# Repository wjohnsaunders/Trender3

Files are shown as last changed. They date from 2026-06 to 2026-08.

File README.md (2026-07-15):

# Trender3

## Introduction

The Trender3 is a printer that can be constructed (mostly) with the parts
from two Ender3s. You will need two additional 2020x290 V-slot extrusions
for the Y axis.

The Trender3 is a custom Voron Trident configured for a 170x170x180 build
volume, with 370x370x420 outer frame dimensions (not including the height
due to feet and skirts). While everything is contained within the outer
frame dimensions, you will need to print a top-hat if you intend to use a
top panel, due to the reduced clearance above the extruder.

Note: A normal 170x170x180 Trident would 410mm between the deck and the top
panels, whereas the Trender3 is 380mm due to the extrusion sizes we have
from the Ender3's. That 30mm loss makes the space above the extruder too
tight for the bowden tube.

## BOM

### Basic BOM
The BOM essentially consists of:
- Two older Ender3s disassembled into parts
- Voron Trident Configurator speced for 170x170x180 (less the parts described below)

### Steppers / Leadscrews
For the A/B steppers you can use the Ender3's extruder steppers (42-40). Make
sure they are the ones with a removable gear and a D shaft. If not you would
need to source some suitable steppers.

For the Z steppers, you can use the X,Y or Z steppers, find 3 that are the same
size (42-34). You don't need a D shaft, or a long shaft, you just need to be able
to remove the pulley/gear from the end. You should have 2 leadscrews and 2 couplers
from the Ender3's, you will need to buy 1 more leadscrew and 1 more Creality style
coupler.

You will need to buy the 3 leadscrew nuts from the Trident BOM, as the Ender3 ones
are not compatible.

Important: Make sure to get leadscrews and nuts with an 8mm lead (4 starts).

### Linear Rails

You will need to buy 3 x MGN12H 220mm and 3 x MGN12H 235mm. The Z axis rails
are 5mm longer than spec so you may not need a spacer/stopper at the top of
the rail (depend on the mix of R1/R2 parts you use). Note: it is recommended
to use a Z2 tolerance rail for X, then Z1 for the others. However Z0 for the
Z axis rails is good as well.

You will need community remixed parts for the MGN12H rails. There are remixes
available for Trident R1 and also for R2, so take your pick.

### PSU and Power Switch

The Ender3 power switch/connector and cord can be reused for mains power. I
have a skirt designed specifically for it.

The 24V 360W PSU from the Ender3 can be used. Both the Meanwell and the other
version fits. If you move to a mains power heated bed you could swap for a lower
power PSU from the Trident BOM. However if you retain the Ender3 heated bed you
will need the power.

## Frame

Refer to the following diagram that shows how the extrusions fit together.

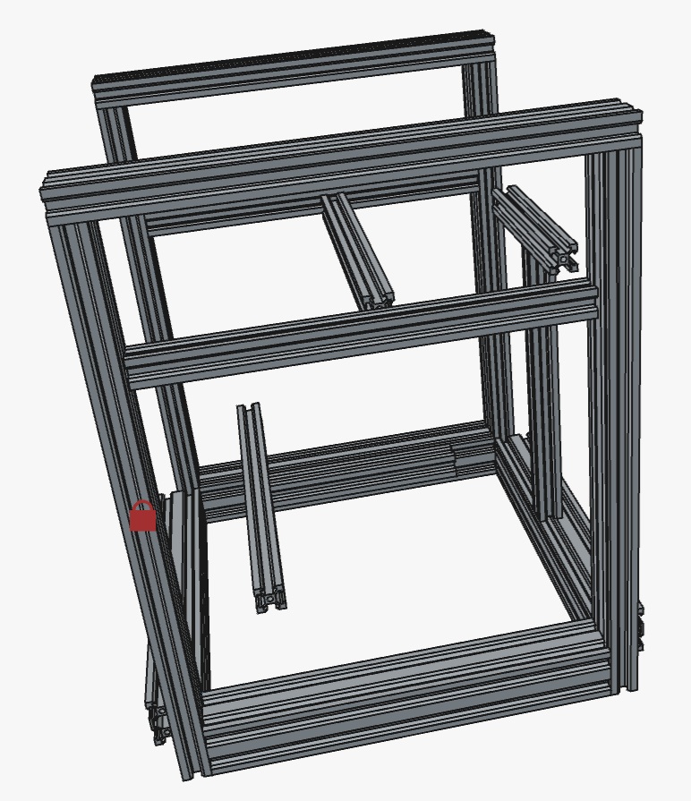
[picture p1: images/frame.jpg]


The 4040 and 2040 Ender3 extrusions are used as-is. However the 4 x 2020
extrusions need to be cut. Cut 1 down to 290mm, and 2 down to 250mm. The last
one should be cut into a 152mm length and a 160mm length. You will need 2
additional 290mm lengths of 2020 for the Y axis, which needs to be sourced
separately. Optionally 2 additional 290mm extrusions to brace the top of
the frame, and make panel installation straightforward.

The frame should be constructed using the blind joint method. Take care to
ensure that the frame is square before a final tighten of the bolts.

You should peel of any rubber feet from the Ender3 extrusions, these will not
be needed and they get in the way of aligning the frame.

Take the time to get the frame correct before starting to attach parts to it.

## X/Y/Z motion Systems

Follow the Trident assembly manual to install all of the parts. The use of
2040 and 4040 extrusions in the frame should not interfere with the install
of the standard Voron Trident parts.

## Heated Bed Options

### Ender3 Bed
The most cost effective approach is to re-use an Ender3 bed. You will not be
able to use all of the bed, however it is still functional for 170x170 prints.

The Ender3 bed should just fit between the front leadscews (tested with R1 Z
axis parts). You will need to replace the large wheel nuts with smaller thumb
(knurled) nuts from the Trident BOM (or just M4 nuts in a pinch).

You will need to drill 2x4mm holes in the X shaped plate that the bed attaches to.
A special tool has been provided to provide a precise drilling location. Drill the
first hole with a 4mm drill in the position as shown in the following picture.

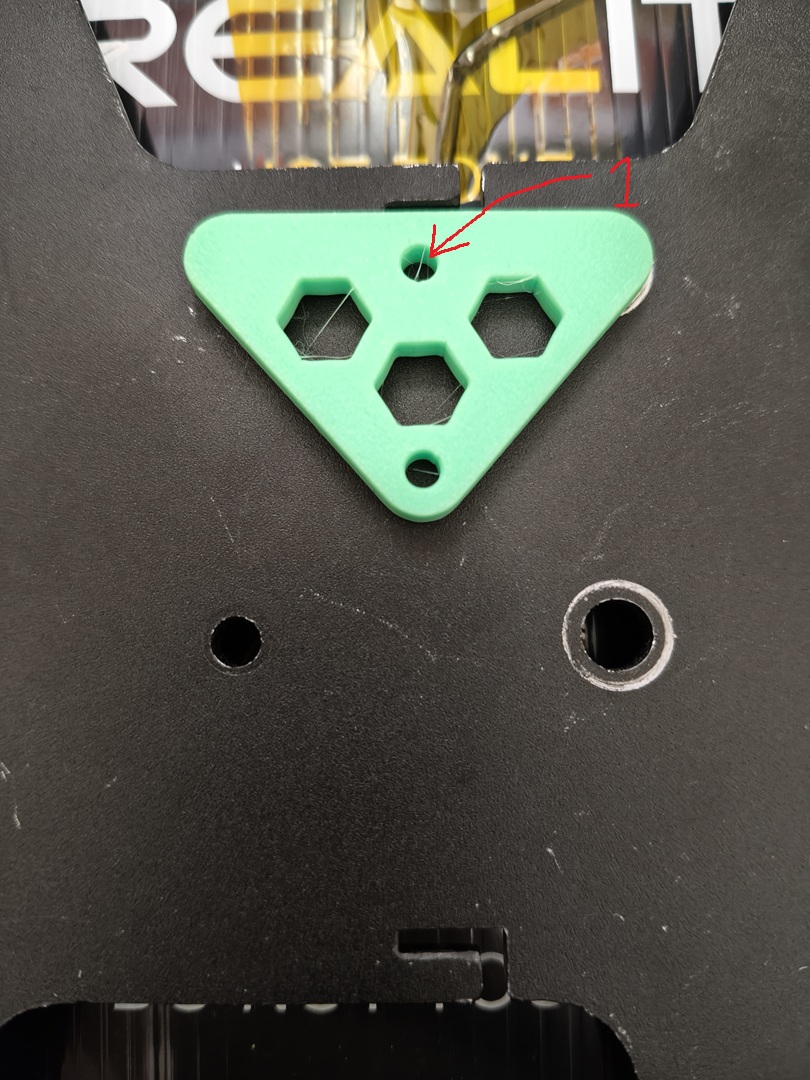
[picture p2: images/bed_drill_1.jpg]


Drill the second hole with a 4mm drill in the position as shown in the following
picture.

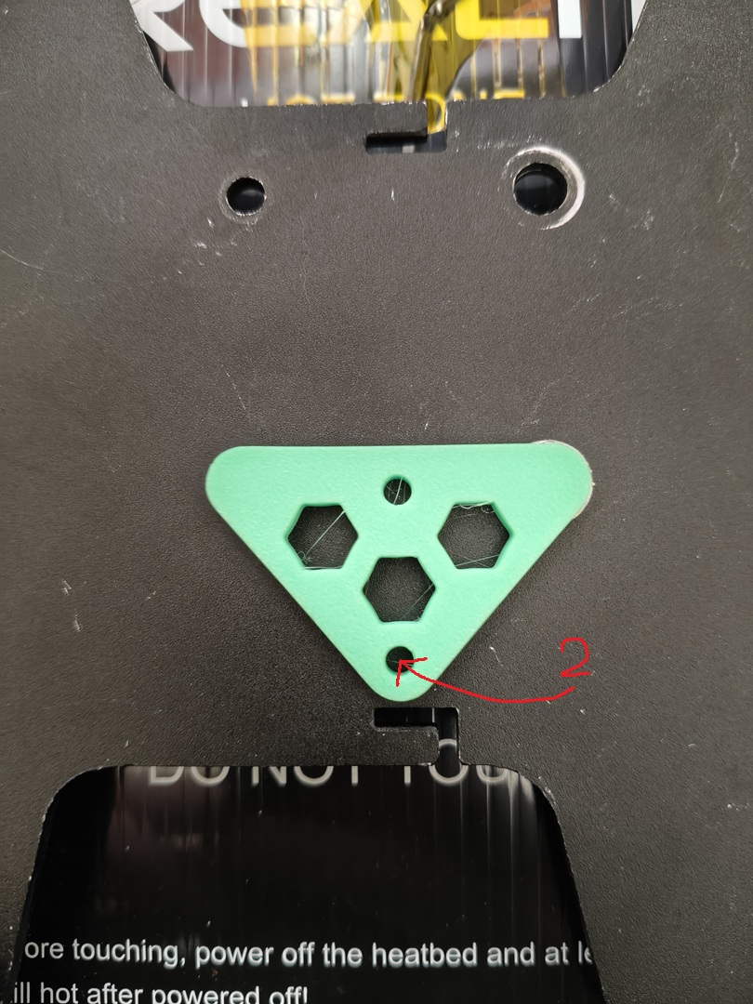
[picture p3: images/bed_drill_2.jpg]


Use M4 bolts and T-nuts from the Ender3 parts box to mount to the extrusion that
runs front to back. You can adjust the position of the bed to your preference,
just make sure that it doesn't hit anything when the Z axis moves.

### MIC-6 Bed

The recommended heated bed is for a 180x180 Salad Fork 3d printer, which is
available from AliExpress along with a silicon heater and PEI build plate. It
is common to see these beds sold with mounting holes for both the Salad Fork
180 and Micron 180 printers.

In the prefered bed position, the front mounting holes will not be aligned with
the extrusion so a bracket is needed. I haven't yet tackled this so I don't have
a solution. I am wondering if a 3D print would handle the heat, but I would like
to come up with a metal bracket.

## Electronics Bay Management

I have gone with the standard Trident DIN rail configuration. I didn't need a
5V supply for the Raspberry Pi as the Fysetc Spider H7 includes a Pi power
cable. Everything is a tight fit, but it does fit.

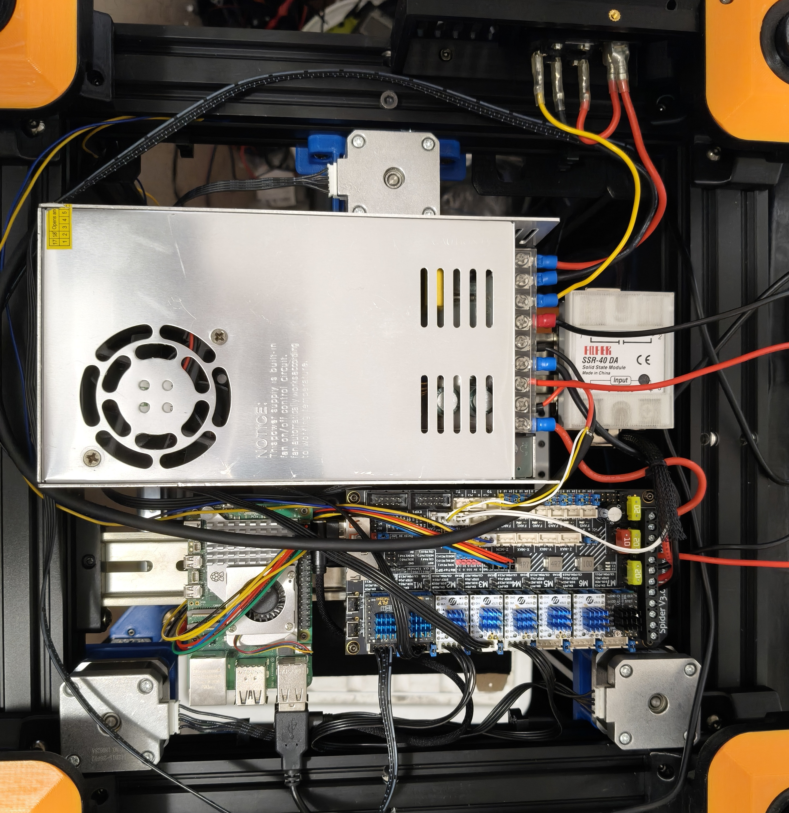
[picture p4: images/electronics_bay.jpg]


There is be an additional 20mm of height in the electronics bay due to the use
of 4040 extrusion. So more space is available if you go up. A mount for the
Raspberry Pi that rotates it 90 degrees would make the fitment less tight.

If I were to do an inverted electronics mod in the future, I would likely go
with an "FT EMS" panel approach to allow flexible placement of different brands
of components. I had a good experience with that on a Duender, and it is used
on Vorons in place of the DIN rails.

## Final thoughts

I have found that Feet and Skirts from "doom cubes" are good inspiration for
what the Trender3 needs. However the small size means that the skirts will not
fit as-is. I have a progressing design for custom skirts and feet for this
project. Some of the skirts are ready now, and I have borrowed some feet that
gets the job done for now.

The toolhead choice is left up to the builder to decide. There are a number
of good choices available for the smaller printers. Just don't make yet
another StealthBurner like I did, so it does work if you insist.

I would recommend an umbilical with a CAN/USB toolhead PCB, to avoid cramming
so many cable chains into something so small. I prefer a swing-arm to support
the umbilical. However there are many Trident solutions to this problem, and
this is a Trident after all, so experiment.

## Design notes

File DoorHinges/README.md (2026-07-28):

# Door Hinges

These door hinges are designed to fit to a 2040 (or 4040) V-Slot extrusion and
allow for the door to swing open 270 degrees and clear panels and panel clips
(7mm clearance provided - which is a Trident 4mm panel clip).

Rather than use adhesive tape, they are designed for holes to be drilled in the
panels, with the hinge screwed on using a reinforcement part to sandwitch the
panel and prevent it cracking.

# Printing

Print 2 or 3 sets for the left, 2 or 3 sets for the right, and the appropriate
number of reinforcement parts.

There are a couple of drill jigs that you can print to guide hole drilling. The
end jig provides 16mm from the edge of the panel (6mm is the overlap of the
extrusion, and 10mm for spacing). However you can use the other jig to place
the holes wherever you want them. Just measure and check clearance to any
other parts that you might have before drilling. If your panel clips are
thicker than 7mm, you might want to position the hinges away from them.

# BOM

4 or 6 3mm x 35mm pins (down to 25mm should still work)
4 or 6 M3x8 SHCS
4 or 6 M4 hammer nuts
8 or 12 M3x8 BHCS

# Assembly

The holes are designed so that the pins are a tight fit into the extrusion
mounts, and a looser fit into the hinge that attaches to the panels. That
allows you to take the doors off and the pins stay in place. That means
you will have to tap the pins into place with a tool.

Use the SHCS and hammer nuts to attach the extrusion mounts loosely.

Use the jig to drill the holes in the panel. Check twice between drilling.
You may want to mock up the positions by using sticky tape first, then drill
when you are satisfied the doors will open properly.

Attach the hinge to the panel by sandwiching the panel between it and the
reinforcement part, use the BHCS to attach. Don't screw down too hard,
just tight is enough.

Fit the doors onto the pins. Adjust the extrusion mount position so that the
doors are positioned correctly, aligned with each other and open smoothly.

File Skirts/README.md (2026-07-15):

# Trender3 Skirts

The skirts are a redesign that moves away from the Trident hexagons.
The additional difference is that the side skirts have the same look
as the front/rear skirts, which allows fingers to grip the sides for
carrying the printer.

I initially wanted to only do a left and rigth skirt from the back and
sides. However a prototype print showed that it was very hard to install
the second skirt, so I went with 3 skirts per side. The up-side was that
the front left/right skirts could also serve the sides, reducing the
number of designs that I needed to do.

## Front

### Print BOM

- 1x Trender3Skirts-MkII-FrontAndSidesStyleA
- 1x Trender3Skirts-MkII-FrontAndSidesStyleB

#### Headless Option
- 1x Trender3Skirts-MkII-CenterDoubleMountingBoltWidth117 (for headless)

#### Trident 12864 Option

- 1x mini12864_case_front
- 1x mini12864_case_rear
- 1x [a]_mini12864_case_front_insert
- 1x [a]_mini12864_case_hinge

Note: Files from Trident STL package

### Description

I have kept the center available for one of the Trident screen options.
Hopfully any screen that fits in the standard space on a Trident will fit.
There is also a no-screen skirt that keeps the Trender3 style for headless
builds.

Measurements: 268 (243 not including the feature)
Front Left/Right width: 75 (62.5 not including the feature)
No-screen skirt width: 117
Trident screen mount width: 117

## Sides

### Print BOM

- 2x Trender3Skirts-MkII-FrontAndSidesStyleA
- 2x Trender3Skirts-MkII-FrontAndSidesStyleB

#### Single Fan Option

- 1x Trender3Skirts-MkII-FanMount60mm
- 1x Trender3Skirts-MkII-FanCarrier60mm
- 1x Trender3Skirts-MkII-FanGrill60mm
- 1x Trender3Skirts-MkII-CenterDoubleMountingBoltWidth113

#### Dual Fans Option

- 2x Trender3Skirts-MkII-FanMount60mm
- 2x Trender3Skirts-MkII-FanCarrier60mm
- 2x Trender3Skirts-MkII-FanGrill60mm

### Description

The front left/right skirts are re-used, and the center skirt carries the
fan. There is a fan option for the standard 6020 Trident fan, but also for
dual 4010 axial fans as used on the Ender3 for the electronics bay cooling
and the hotend cooling.

Measurements: 264 (239)
Front Left/Right width: 75 (62.5 not including the feature)
Fan skirt width: 113

## Back

### Print BOM

- 1x Trender3Skirts-MkII-LeftSideRear-Ender3
- 1x Trender3Skirts-MkII-RightSideRear
- 1x Trender3Skirts-MkII-CenterSingleMountingBoltWidth41

### Description

The back of the Trender3 has a skirt with cutouts for the Ender3 inlet.
It has a narrow center skirt in addition to the right side skirt. It is
the only side that doesn't follow the narrow sides and wide center style,
but it is discated by needing an inlet, and a center inlet is blocked by
the rear stepper.

Measurements: 268 (243 not including the feature)
Back Left/Right width: 113 (100.5 not including the feature)
Back Center width: 41

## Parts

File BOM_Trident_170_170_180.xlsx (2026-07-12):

Category | Description | Qty | Notes
Fasteners | 2020 Drop-in T-nut, M5 | 69
 | M5x40 BHCS | 4
 | M5x30 BHCS | 4
 | M5x16 BHCS | 58
 | M5x10 BHCS | 45
 | M5 1mm Spacer | 24
 | M5xD7xL6 Heat Set | 15
 | M4x6 BHCS | 7
 | M4 Knurled Nut | 3
 | M3x50 SHCS | 2
 | M3x40 SHCS | 9
 | M3x30 SHCS | 13
 | M3x25 SHCS | 10
 | M3x20 SHCS | 3
 | M3x16 SHCS | 27
 | M3x12 SHCS | 73
 | M3x8 SHCS | 128
 | M3x6 BHCS | 59
 | M3x10 FHCS | 2
 | M3x6 FHCS | 17
 | M3 Locknut | 6
 | M3 Washer | 4
 | 2020 Drop-in T-nut, M3 | 74
 | M3 Hammerhead T-Nut | 55
 | M3xD5xL4 Heat Set | 109
 | M2x10 Selftapping screw | 17
Motion | GT2 20T Pulley (5mm ID 6mm W) | 3
 | GT2 20T Toothed Idler (5mm ID 6mm W) | 2
 | F695 Bearing | 26
 | GE5C Spherical Bearing | 3
 | TR8x4 Leadscrew Nut | 3
 | 5x30mm Shaft | 1
 | BMG Extruder Components Kit | 1
 | Linear Rail MGN12H 220mm | 1 | X
 | Linear Rail MGN9H 220mm | 2 | Y
 | Linear Rail MGN9H 230mm | 3 | Z - 235mm
 | GT2 Open Belt LL-2GT-6 (6mm wide) - 1370mm | 2
Vibration Management | Rubber Foot | 4
Electronics | NEMA17 Motor 17HS19-2004S | 2
 | SPDT KW10 Limit Micro Switch | 3
 | Omron TL-Q5MC2 - NPN, NC, 5mm Sense Inductive Probe | 1
 | E3D V6 Bowden Hotend Kit (24V) | 1
 | 50x50x15 Centrifugal Fan (24V) | 1
 | 40x40x10 Axial Fan (24V) | 1
 | Mini 12864 Display | 1
 | Medium Blow Fuse 5 x 20mm: 4A for 220V mains or 8A for 120v | 2
 | TycoElectronics 10EGG1-2 Filtered Power Inlet | 1
 | ZF - Rocker Switches DPST 16A | 1
 | Keystone CAT6 Insert (Optional) | 1
 | 60x60x20 Fan (24V) | 3
 | 6 Stepper Controller (or multiple to equal 6+ steppers) | 1
 | TMC2209 Stepper Motor Driver | 6
 | Raspberry Pi 4 | 1
 | Mean Well LRS-200-24 PSU | 1
 | Mean Well TBC-09 Terminal Cover | 1
 | Mean Well RS-25-5 PSU | 1
 | Omron G3A-210B-DC5 SSR | 1
 | DIN Rail Mount Bracket for G3A SSR | 1
 | BAT85 Diode | 1
 | C13 Power Cord | 1
 | Thermal Fuse (150C) | 1
 | NEMA14 Motor 36STH20-1004AHG | 1
 | NeoPixel RGBW Mini Button PCB | 3
 | NEMA17 TR8x4 230mm Linear Stepper | 3 | Use leadscrews and couplers
Misc | PTFE Tube (4mm OD 2mm ID | Toolhead) - 1m | 1
 | 3M VHB Tape 5952 | 1
 | Single Sided Foam Tape (3mm Thick, 5-6mm Wide) | 9
 | Loctite Blue Threadlocker Stick | 1
 | Mobil EP2 Grease | 1
 | Tesa Wire Loom Harness Tape | 1
 | 6x3mm Neodymium Magnet | 8
 | PTFE Tube (4mm OD 3mm ID) - 1m | 1
Cables | Nylon Cable Ties 4" | 40
 | 1/2" Braided Cable Sheathing (ft) | 5
 | 18AWG High-Flex Wire (ft) | 10
 | 20AWG High-Flex Wire (ft) | 10
 | 22-24AWG High-Flex Wire (min 19 strand)(ft) | 100
 | Spade Crimp Terminal 4.8mm Female | 10
 | JST XH Connector Plug 4 Position | 5
 | JST XH Connector Plug 3 Position | 4
 | JST XH Connector Plug 2 Position | 2
 | JST XH Female Pin | 40
 | MicroFit3 Connector Plug 4 Position | 2
 | MicroFit3 Connector Plug 3 Position | 1
 | MicroFit3 Connector Plug 2 Position | 5
 | MicroFit3 Connector Receptacle 4 Position | 2
 | MicroFit3 Connector Receptacle 3 Position | 1
 | MicroFit3 Connector Receptacle 2 Position | 5
 | MicroFit3 Female Pin | 40
 | MicroFit3 Male Pin | 40
 | 10x11 Cable Chain - 1m, 3 End Sets | 1
 | WAGO 221-415 Lever-Nuts | 3
 | WAGO 221-412 Lever-Nuts | 3
Frame | DIN 3 Rails (35mm W) - 290mm | 2
 | Misumi HFSB5-2020-430-LCP-RCP-AV290 | 4 | 2040x400 (frame corners)
 | Misumi HFSB5-2020-290-TPW | 3 | 4040x290 (frame lower front/sides)
 | Misumi HFSB5-2020-290-AH145-TPW | 1 | 4040x290 (frame lower back)
 | Misumi HFSB5-2020-290-TPW | 2 | 2020x290 (Y axis)
 | Misumi HFSB5-2020-290-TPW | 2 | 2040x330 (frame top sides)
 | Misumi HFSB5-2020-290-TPW | 2 | 2020x290 (frame top front/back)
 | Misumi HFSB5-2020-260-LTP | 1 | 2020x260 (Z axis back)
 | Misumi HFSB5-2020-160 | 1 | 2020x160 (A/B connector back)
 | Misumi HFSB5-2020-250 | 1 | 2020x250 (X axis)
 | Misumi HFSB5-2020-152-LTP | 1 | 2020x152 (bed 1)
 | Misumi HFSB5-2020-290-AH145 | 1 | 2020x290 (bed 2)
Panels | ~~Coroplast Sheet - 289x289x4 mm~~ | 2 | 289x289x4mm | deck/bottom
 | ~~Coroplast Sheet - 302x402x4 mm~~ | 1 | 302x372x4mm | rear
 | ~~Acrylic Sheet Clear - 151.5x403x3 mm~~ | 2 | 151.5x373x3mm | front doors
 | ~~Acrylic Sheet Clear - 303x403x3 mm~~ | 2 | 303x373x3mm | sides
 | ~~Acrylic Sheet Clear - 303x303x3 mm~~ | 1 | 303x303x3mm | top
Buildplate | 3M 468MP Adhesive Sheet - 7"x7" | 1 | 180x180 Saladfork/Micron
 | PEI 0.04" Sheet - 7"x7" | 1
 | MIC6 5/16" Plate - 7"x7" | 1
 | Keenovo Silicone AC Heater w/ thermistor - 120x120mm (200W) | 1

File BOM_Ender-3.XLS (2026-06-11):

Ender-3 BOM
Part Code | Part Name | Specification | UNIT | Qty
200101027 | Control panel | 1284P | PCS | 1
200102010 | LCD |  | PCS | 1
400101002 | E plate | 2.5mm | PCS | 1
400101005 | Y Motor holder | 3mm | PCS | 1
400101006 | X Adjustment Block | 3mm | PCS | 1
400101027 | Z Stent | 3.0mm | PCS | 1
400101029 | Fan cover | 0.8mm | PCS | 1
400101081 | Support frame | 2.0mm | PCS | 1
400101103 | E motor bracket | 2.5mm，B1 | PCS | 1
400101104 | X motor bracket | 3mm，B1 | PCS | 1
400101130 | Sheetmetal enclosure bottom | 0.8MM | PCS | 1
400101131 | Sheetmetal enclosure top | 0.8MM | PCS | 1
400101133 | LCD support | 2MM | PCS | 1
400101007 | Y Adjustment Block | 3mm | PCS | 1
400101129 | Y plate | 4mm | PCS | 1
400102065 | 2020 Top Profile | 20*20-L330 | PCS | 1
400102066 | 2020 X Profile | 20*20-L345 | PCS | 1
400102067 | 2040 Y Profile | 20*40-L330 | PCS | 1
400102068 | 2040 Right Profile | 20*40-L400 | PCS | 1
400102069 | 2040 Left Profile | 20*40-L400 | PCS | 1
400102070 | 4040 Central Profile | 40*40-L250 | PCS | 1
400102071 | 4040 Left Profile | 40*40-L290 | PCS | 1
400102072 | 4040 Right Profile | 40*40-L290-2 | PCS | 1
400103001 | E gear | D11-40 | PCS | 1
400104004 | Heat block | 20*20*10 | PCS | 1
400105008 | Radiator | 12*20*27.8mm,2*M3 | PCS | 1
400106003 | nozzle | 0.4mm | PCS | 2
400107006 | Catheter | D7-M6-L28mm | PCS | 1
400108001 | Spacers for rollers | D8-d5-H-8.35mm | PCS | 11
400108002 | Eccentric column | D7.2-d5-H-8.35mm | PCS | 5
400201001 | 42-34 Motor | JK42HS34-0844YA-03F | PCS | 3
400201004 | 42-40 Motor | JK42HS40-1004AC-01F | PCS | 1
400202002 | 624U Pillow | 624U | PCS | 1
400202003 | F688ZZ Pillow | F688ZZ | PCS | 4
400202004 | 625ZZ Pillow | 625ZZ | PCS | 26
400204002 | Extrusion Spring | 1.1*8*L22 | PCS | 5
400205002 | M2*8 Socket Head Screw | M2*8 | PCS | 2
400205003 | M2*10 Socket Head Screw | M2*10 | PCS | 2
400205007 | M3*18 Socket Head Screw | M3*18 | PCS | 1
400205013 | M4*8Socket Head Screw | M4*8 | PCS | 7
400205014 | M4*10 Socket Head Screw | M4*10 | PCS | 2
400205015 | M4*16 Socket Head Screw | M4*16 | PCS | 4
400205018 | M3*3 screw | M3*3 | PCS | 4
400205019 | M4 screw | M4 | PCS | 4
400205021 | M3*4 Pan Head Screw | M3*4 | PCS | 1
400205029 | M3*6 Pan Head Screw | M3*6 | PCS | 18
400205031 | M3*10 Pan Head Screw | M3*10 | PCS | 12
400205032 | M3*16 Pan Head Screw | M3*16 | PCS | 5
400205044 | M5*8 Pan Head Screw | M5*8 | PCS | 8
400205053 | M5*30 Pan Head Screw | M5*30 | PCS | 10
400205055 | M5*40 Pan Head Screw | M5*40 | PCS | 3
400205060 | M3*10 Pan Head Screw | M3*10-P | PCS | 1
400205068 | M4*14 Pan Head Screw | M4*14-P | PCS | 2
400205074 | M4*35 Flush Head Screw | M4*35-P | PCS | 4
400205097 | M5 Self-locking nut | M5 | PCS | 13
400205098 | M8 Self-locking nut | M8 | PCS | 2
400205101 | M4 T-Slot Nut | M4T | PCS | 8
400205102 | M5 T-Slot Nut | M5T | PCS | 3
400205105 | M3 Split Washer | M3 | PCS | 6
400205106 | M4 Split Washer | M4 | PCS | 7
400205107 | M5 Split Washer | M5 | PCS | 12
400205109 | M5 washer | M5 | PCS | 5
400205110 | M5 washer1 | 5*8*1 | PCS | 13
400205111 | z nut | T8*8 | PCS | 1
400205122 | M4*20 Socket Head Screw | M4*20 | PCS | 3
400205140 | M4*18 Pan Head Screw | M4*18-P | PCS | 2
400205141 | M3*40 Pan Head Screw | M3*40-P | PCS | 4
400205144 | M3*18 Pan Head Screw | M3*18-P | PCS | 2
400205148 | M4*16 Screw |  | PCS | 5
400205153 | M3*6 Screw | M3*6 | PCS | 2
400205163 | M5*25 Socket Head Screw | M5*25 | PCS | 6
400205165 | M5*40 Socket Head Screw | M5*40 | PCS | 2
400205166 | M5*45 Socket Head Screw | M5*45 | PCS | 10
400205176 | M8*35 Pan Head Screw | M8*35 | PCS | 2
400206017 | Z threaded rod | T8*8-L365mm | PCS | 1
400208004 | Z coupler | D5*8 | PCS | 1
400210001 | Pneumatic joint | D4M8 | PCS | 1
400210002 | M6 Pneumatic joint | KJH04-06 | PCS | 2
400211009 | 2GT-pulley | 2GT-d5-20-6mm | PCS | 2
400212037 | X belt | 2M-W6-L786mm | PCS | 1
400212038 | Y belt | 2M-W6-L743mm | PCS | 1
400214001 | Copper cover | D8-0.8 | PCS | 4
400301008 | 24V15A power supply | 24V 15A | PCS | 1
400302026 | Hot bed | 24V，235*235mm，220W | PCS | 1
400303006 | Nozzle thermistor | D1.8-L1000mm-100K | PCS | 1
400303022 | Bed thermistor | D1.8-L700mm-100K | PCS | 1
400304001 | limit switch | 3PIN | PCS | 3
400305007 | power switch | 10A | PCS | 1
400306127 | Red silicone wire | 16号-L170mm | PCS | 1
400306128 | Yellow silicone wire | 18号-L170mm | PCS | 1
400306145 | Black silicone wire | 16号-L170mm | PCS | 1
400306217 | Hot bed line | 16号-L500mm | PCS | 1
400306221 | Red silicone wire | 16号-L90mm, | PCS | 1
400306222 | Main board line | 16号-L310mm,XT60 | PCS | 1
400306223 | power line | 16号-L170mm,XT60 | PCS | 1
400306224 | X,E Motor Line | Motor Line L670mm，Limit Line L750mm | PCS | 1
400306225 | Y Motor Line | L420mm | PCS | 1
400306226 | Z Motor Line | Motor LineL280mm，Limit Line L180mm | PCS | 1
400306228 | Display line | 10pin,L470mm | PCS | 1
400307001 | lcd Knob |  | PCS | 1
400308002 | Heater | 24V，40W-L1000MM，Φ6*20 | PCS | 1
400309032 | Cold section fan | 24V-4010-L1000-7600r | PCS | 1
400309044 | Nozzle fan | 24V-4010-L1000-5800r | PCS | 1
400309045 | Case fan | 24V-4010-L150mm | PCS | 1
400402010 | Z motor bracket |  | PCS | 1
400402020 | 2020 Endcap | 2020 | PCS | 2
400402023 | Nozzle fan duct |  | PCS | 1
400402028 | Power holder | 2mm | PCS | 1
400402032 | Y limit switch bracket | ABS | PCS | 1
400402033 | Z limit switch bracket | ABS | PCS | 1
400403003 | Rollers |  | PCS | 13
400403004 | Support tube |  | PCS | 1
400403005 | M30 Plastic nut | M30*6.5 | PCS | 2
400404030 | Hot bed wire bracket |  | PCS | 1
400404031 | Hot bed line support cover |  | PCS | 1
400404032 | E idler tensioner |  | PCS | 1
400404033 | E housing |  | PCS | 1
400404038 | X limit switch bracket | ABS | PCS | 1
400404040 | Hand Twisted Nut | D60mm | PCS | 4
400404041 | 4040 Endcap | ABS | PCS | 2
400406006 | Foot pads | 20*40mm*3mm | PCS | 4
400407013 | D4 Teflon tube | D4-d2-L400mm | PCS | 1
400409003 | Silk pole cover | T8*8 | PCS | 1
400501034 | Linear tube | W8-L450mm | PCS | 1
400501035 | Linear tube | W8-L950mm | PCS | 1
400504007 | Fan cover sticker |  | PCS | 1
400504008 | Product Qualification Certificate |  | PCS | 1
400505021 | Fiber board | 235*235*1.0mm | PCS | 1
400506001 | Scissor |  | PCS | 1
400506002 | shovel |  | PCS | 1
400506005 | 1.5# Hexagonal wrench inside |  | PCS | 1
400506006 | 2# Hexagonal wrench inside |  | PCS | 1
400506007 | 2.5# Hexagonal wrench inside |  | PCS | 1
400506008 | 3# Hexagonal wrench inside |  | PCS | 1
400506009 | 4# Hexagonal wrench inside |  | PCS | 1
400506011 | screwdriver |  | PCS | 1
400506016 | power cord |  | PCS | 1
400506020 | needle |  | PCS | 1
400506029 | tie | 4*150mm | PCS | 10
400506035 | 6# Open wrench |  | PCS | 1
400506036 | 8-10# Open wrench |  | PCS | 1
400506044 | Clip | 6#,15mm | PCS | 4
500101065 | Bubble cotton | 495*380*160mm | PCS | 1
500201001 | Self-Sealing bag | 6cm*9cm*0.8mm | PCS | 14
500201002 | Self-Sealing bag | 9cm*13cm*0.8mm | PCS | 1
500201004 | Self-Sealing bag | 15cm*20cm*0.8mm | PCS | 2
500201006 | Self-Sealing bag | 18cm*26cm*0.6mm | PCS | 1
500201008 | Prevention electrostatic bag | 15cm*20cm | PCS | 1
500301056 | paper box | 510*400*190mm | PCS | 1
500601001 | Opinion Card |  | PCS | 1
600101011 | Instruction |  | PCS | 1
600401004 | Memory Card | 8G | PCS | 1
600501001 | Card Reader |  | PCS | 1
600601016 | warranty card |  | PCS | 1
600601023 | Manufacture of numbered stickers | 60*10.4MM | PCS | 1
600601026 | Specification stickers | 65*40mm | PCS | 1
600601058 | Facebook code sticker | 41*41mm | PCS | 1
700206003 | Testing consumables | 5M | PCS | 1
700301044 | High temperature cotton | 20*50mm | PCS | 1
700301051 | gummed paper | 30*60 | PCS | 3
700301054 | gummed paper | 60*60mm | PCS | 1
700301056 | High temperature cotton | 50*60mm | PCS | 1

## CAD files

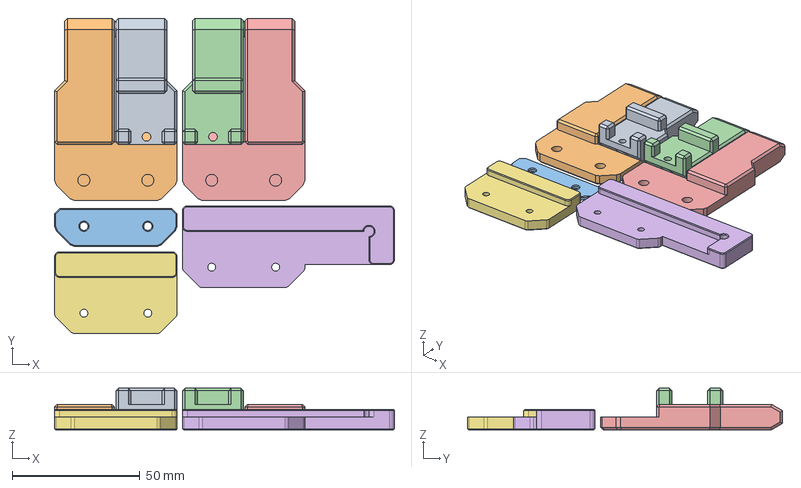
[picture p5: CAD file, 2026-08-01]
DoorHinges/CAD/DoorHinges2040.FCStd
133.0 x 123.3 x 16.3 mm
ExtrusionMountLeft
PanelMountLeft
PanelReinforcement
ExtrusionMountRight
PanelMountRight
DrillingJigEnds
DrillingJig

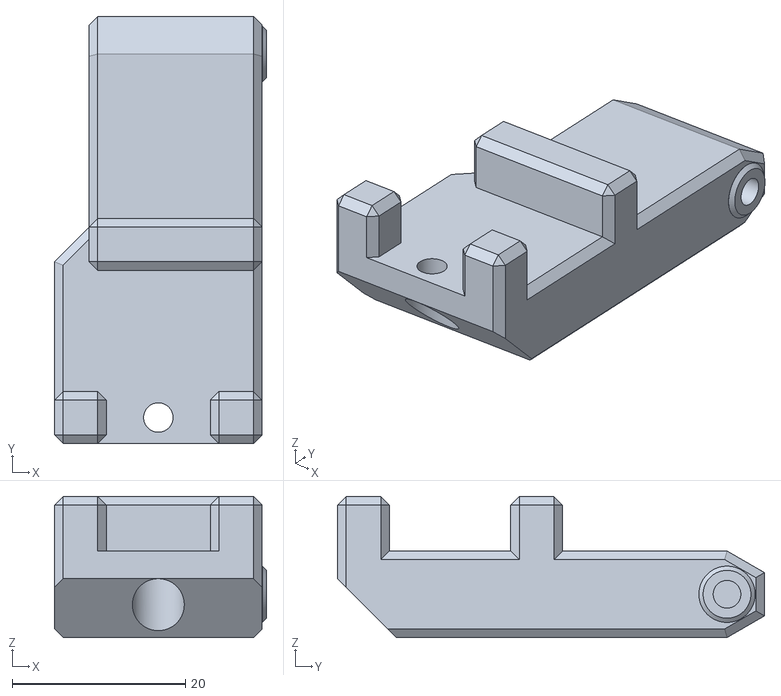
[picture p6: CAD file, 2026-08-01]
DoorHinges/STL/DoorHinges2040-ExtrusionMountRight.stl
24.5 x 49.3 x 16.3

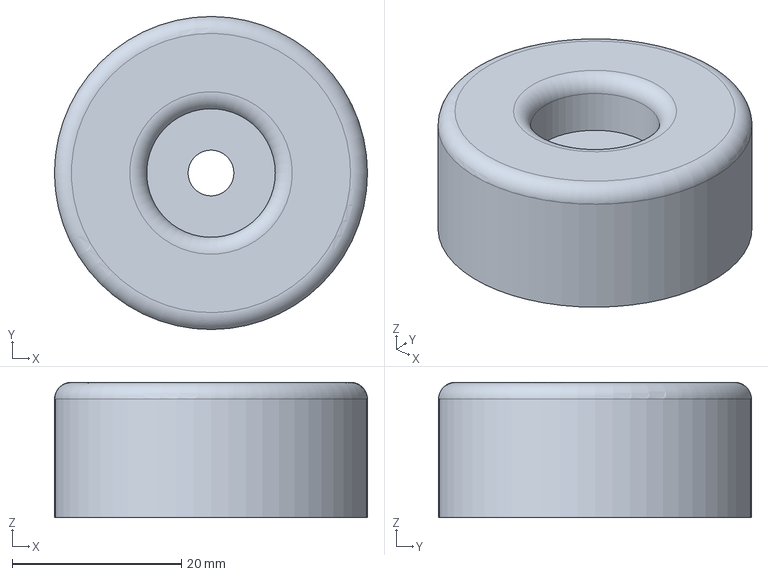
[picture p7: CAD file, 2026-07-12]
Skirts/CAD/TpuFeet.FCStd
37.0 x 37.0 x 16.0 mm

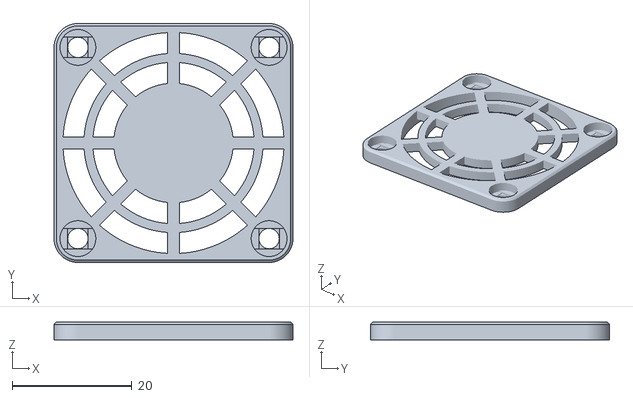
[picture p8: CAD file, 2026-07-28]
Skirts/STL/Trender3Skirts-MkII-FanGrill40mm.stl
40.0 x 40.0 x 3.00

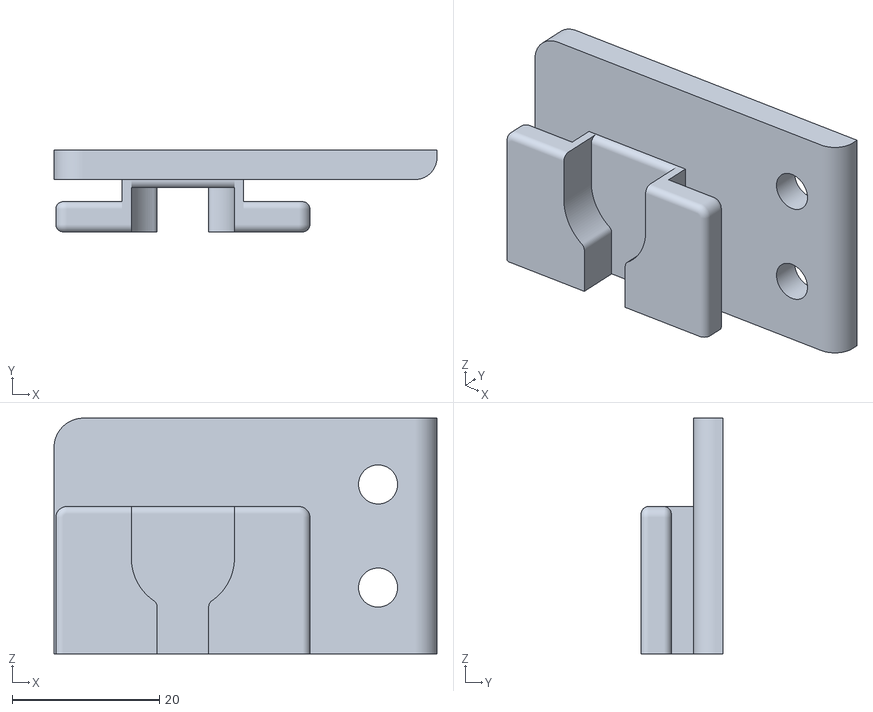
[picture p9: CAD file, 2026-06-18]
STL/ad5x-spool-holder-bracket-OffsetMountRight.stl
52.0 x 11.1 x 32.0

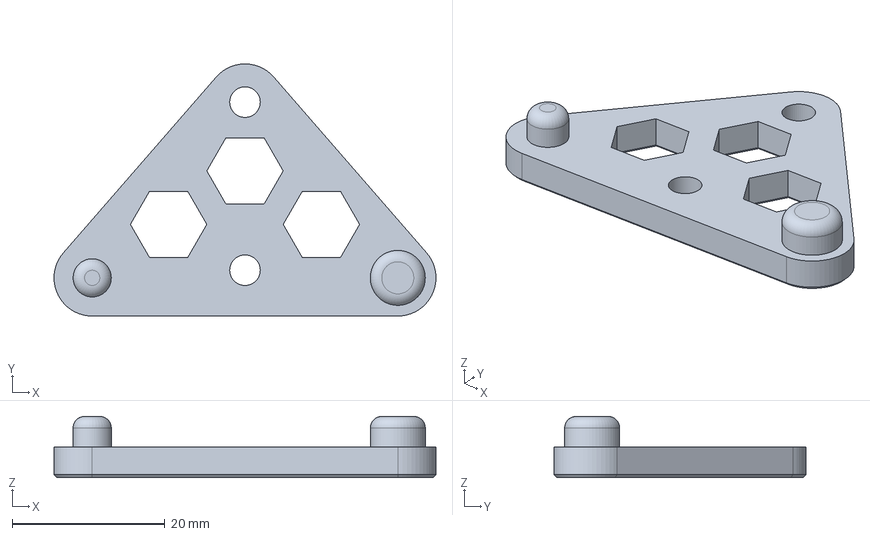
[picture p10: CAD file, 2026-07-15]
Tools/CAD/Ender3Bed.FCStd
50.0 x 33.0 x 8.00 mm

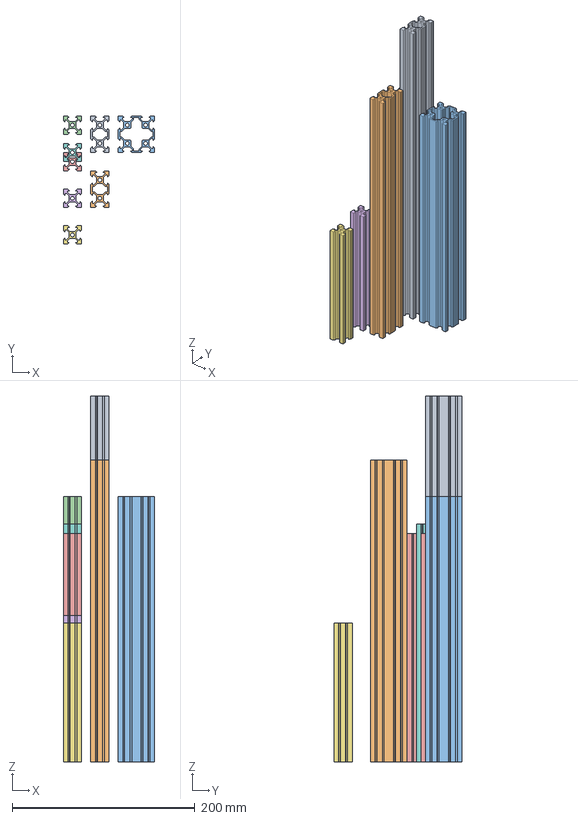
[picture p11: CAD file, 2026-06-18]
CAD/Trender3_Frame_Extrusions.FCStd
100.0 x 140.0 x 400.0 mm
2040x400 (uprights)
2040x330 (top left/right)
4040x290 (bottom left/right/front/back)
2020x290 (Y axis, bed 1)
2020x250 (X axis)
2020x160 (X/Y rear horizontal)
2020x152 (bed 2)
2020x260 (Z rear vertical)

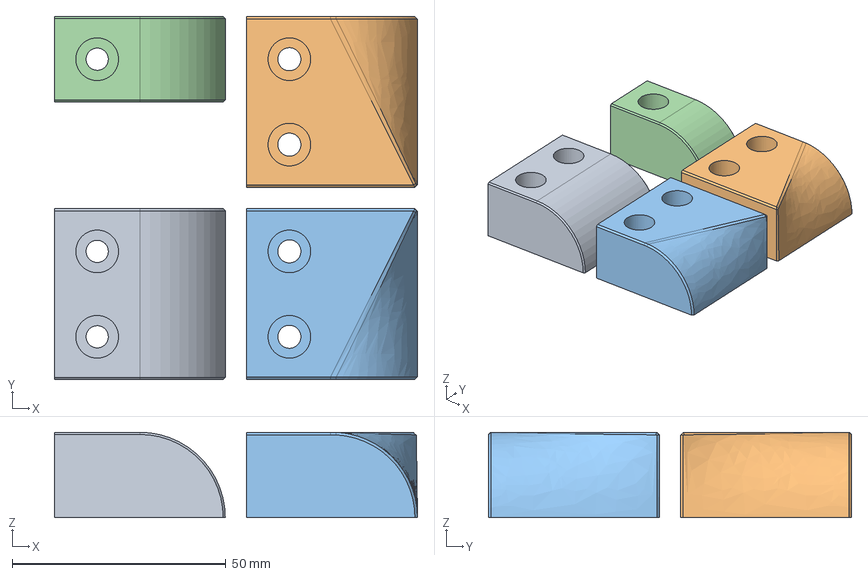
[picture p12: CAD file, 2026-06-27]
Skirts/CAD/CornerFinish.FCStd
85.0 x 85.0 x 20.0 mm
Bullnose4040
BlendSquareToBullnose_A
BlendSquareToBullnose_B
Bullnose2040

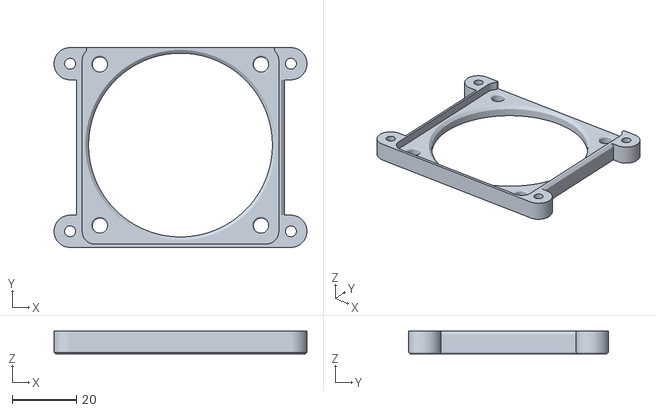
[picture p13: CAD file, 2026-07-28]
Skirts/STL/Trender3Skirts-MkII-FanCarrier60mm.stl
78.5 x 62.0 x 7.00

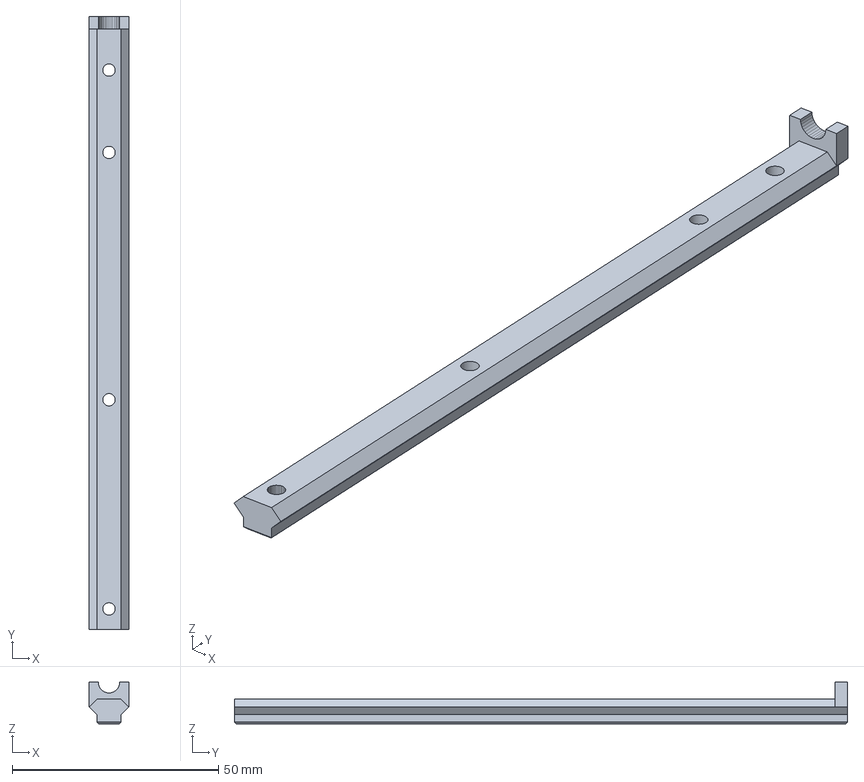
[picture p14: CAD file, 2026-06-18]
Tools/CAD/DrillJig90mm.FCStd
9.60 x 148.8 x 10.1 mm

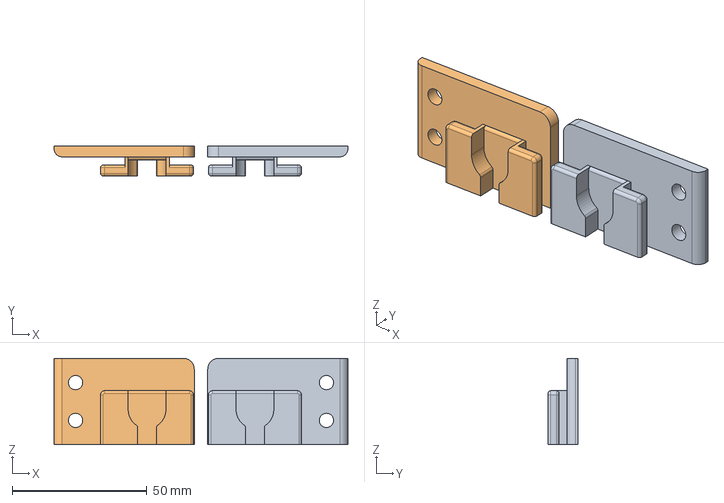
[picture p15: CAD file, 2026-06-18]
CAD/ad5x-spool-holder-bracket.fcstd
109.0 x 11.1 x 32.0 mm
OffsetMountRight
OffsetMountLeft

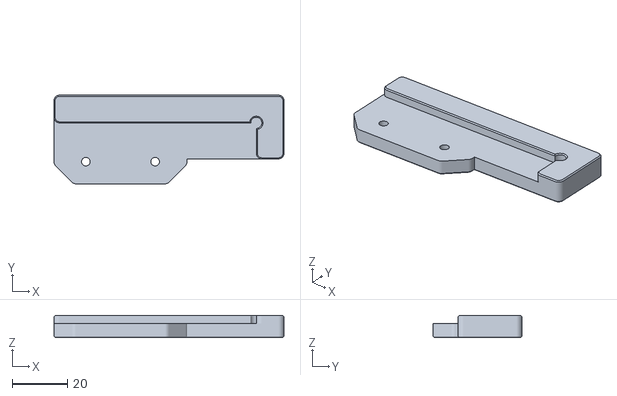
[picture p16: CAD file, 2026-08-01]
DoorHinges/STL/DoorHinges2040-DrillingJigEnds.stl
83.0 x 32.0 x 8.00

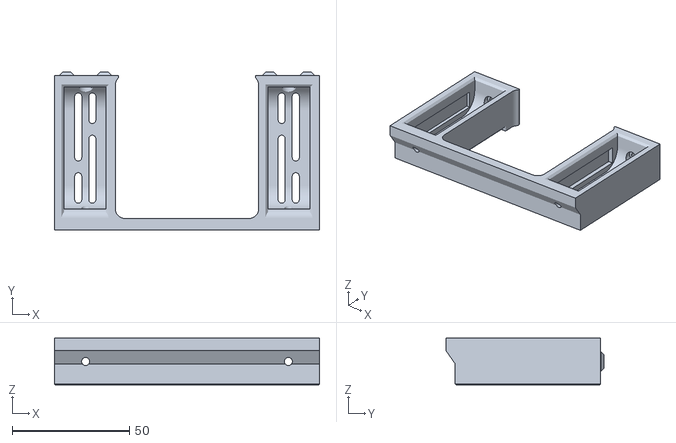
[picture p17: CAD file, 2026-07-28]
Skirts/STL/Trender3Skirts-MkII-FanMount60mm.stl
113.0 x 67.5 x 20.0

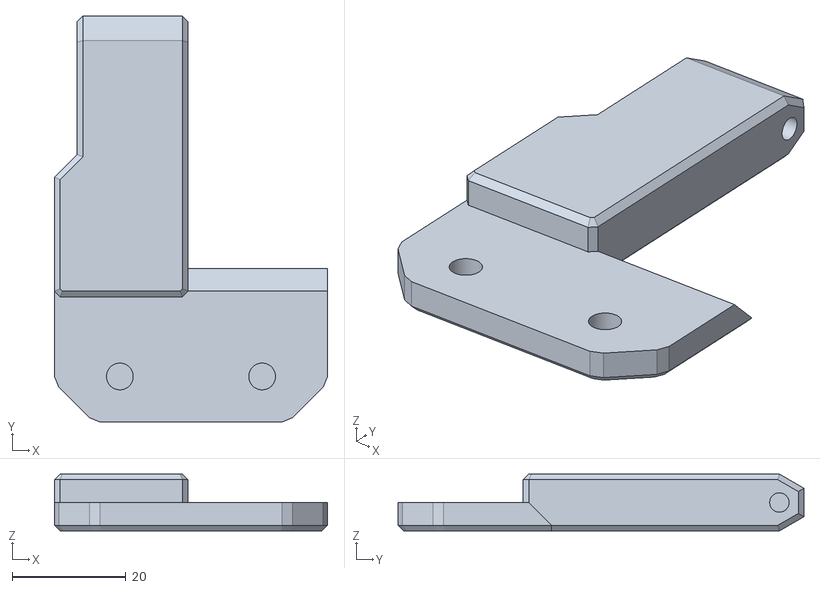
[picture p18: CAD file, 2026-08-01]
DoorHinges/STL/DoorHinges2040-PanelMountLeft.stl
48.0 x 71.3 x 10.0

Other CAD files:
CAD/Trender3_Frame_Assembly.FCStd
Tools/STL/Ender3Bed-DrillingJig.stl
DoorHinges/STL/DoorHinges2040-ExtrusionMountLeft.stl
STL/ad5x-spool-holder-bracket-OffsetMountLeft.stl
DoorHinges/STL/DoorHinges2040-DrillingJig.stl
DoorHinges/STL/DoorHinges2040-PanelMountRight.stl
DoorHinges/STL/DoorHinges2040-PanelReinforcement.stl
Skirts/STL/CornerFinish-BlendSquareToBullnose_A.stl
Skirts/STL/CornerFinish-BlendSquareToBullnose_B.stl
Skirts/STL/CornerFinish-Bullnose2040.stl
Skirts/STL/CornerFinish-Bullnose4040.stl
Skirts/STL/TpuFeet-Trender3.stl
Skirts/STL/Trender3Skirts-MkII-CenterDoubleMountingBoltWidth113.stl
Skirts/STL/Trender3Skirts-MkII-CenterDoubleMountingBoltWidth117.stl
Skirts/STL/Trender3Skirts-MkII-CenterSingleMountingBoltWidth41.stl
Skirts/STL/Trender3Skirts-MkII-FanGrill60mm.stl
Skirts/STL/Trender3Skirts-MkII-FanMount2x40mm.stl
Skirts/STL/Trender3Skirts-MkII-FrontAndSidesStyleA.stl
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

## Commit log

2026-06-11 Initial concept upload
    [BOM_Ender-3.XLS, BOM_Trident170.xlsx, Trender3_Frame_Assembly.FCStd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]
2026-06-11 Update README with extrusion cutting instructions
    Added instructions for cutting 2020 extrusions for the frame.
2026-06-11 Make X axis and Z axis extrusions movable in the assembly.
    [Trender3_Frame_Assembly.FCStd, Trender3_Frame_Extrusions.FCStd]
2026-06-18 Add miscellaneous modified parts - main part is power inlet for Ender3 switch assembly
    [BOM_Trident170.xlsx, CornerFinish.FCStd, CornerFinishM5x16.stl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]
2026-06-18 Add Trident R2 motion parts to the assembly.
    [Trender3_Frame_Assembly.FCStd, Trender3_Frame_Extrusions.FCStd]
2026-06-22 Using Duskshade Unibody Skirts from mjonuschat. Designed shorter front and rear skirts, however using corners as-is.
    [CornerFinish-BlendSquareToBullnose_A.stl, CornerFinish-BlendSquareToBullnose_B.stl, CornerFinish-Bullnose.stl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]
2026-06-27 More work on skirts and corner finish pieces. Added feet accent parts.
    [BOM_Trident170.xlsx, BOM_Trident_170_170_180.xlsx, CornerFinish-Bullnose.stl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]
2026-07-12 New MkII skirts - sides still missing. Update BOM info.
    [BOM_Trident_170_170_180.xlsx, InletSkirtEnder3.FCStd, InletSkirtEnder3.stl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]
2026-07-15 Update README and complete initial skirts design.
    [InletSkirtEnder3.FCStd, InletSkirtEnder3.stl, Trender3Skirts-MkII-CenterDoubleMountingBoltWidth113.step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]
2026-07-15 Large re-shuffle of files. Added drilling jig for Ender3 bed.
    [CornerFinish-BlendSquareToBullnose_A.stl, CornerFinish-BlendSquareToBullnose_B.stl, CornerFinish-Bullnose2040.stl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]
2026-07-28 Add a dual 40mm fan skirt. Update 60mm fan skirt to allow cable routing. Add a door hinge.
    [DoorHinges2040-DrillingJig.stl, DoorHinges2040-DrillingJigEnds.stl, DoorHinges2040-ExtrusionMountLeft.stl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]
2026-08-01 Make ends narrower so it doesn't look so blocky.
    [DoorHinges2040-DrillingJigEnds.stl, DoorHinges2040-ExtrusionMountLeft.stl, DoorHinges2040-ExtrusionMountRight.stl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]
